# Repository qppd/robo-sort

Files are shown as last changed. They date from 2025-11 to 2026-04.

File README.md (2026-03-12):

# RoboSort: Advanced Automated Waste Segregation with AI Vision & LIDAR







## Overview
RoboSort is an intelligent automated waste segregation system designed to efficiently separate paper and plastic waste materials using a robotic arm, stepper motor positioning, and cutting-edge AI technology. The project addresses the growing need for automated waste management by combining computer vision, robotics, embedded systems, and LIDAR sensing to accurately identify and sort recyclable materials.

Integrating both Arduino and Raspberry Pi platforms, RoboSort combines mechanical, electrical, and software components for a robust, scalable solution suitable for educational institutions, recycling facilities, and smart waste management applications. The system now features advanced YOLO-based object detection, 360° LIDAR environmental awareness, and ROS2-based autonomous navigation with LiDAR odometry for precise robot localization and mapping.

## Table of Contents
- [Overview](#overview)
- [Architecture](#architecture)
- [System Diagrams](#system-diagrams)
- [Serial Communication Protocol](#serial-communication-protocol)
- [Features](#features)
- [Hardware Requirements](#hardware-requirements)
- [Software Components](#software-components)
- [Installation](#installation)
- [Usage](#usage)
- [Wiring Diagram](#wiring-diagram)
- [Hardware Models](#hardware-models)
- [Project Structure](#project-structure)
- [AI Vision System Configuration](#ai-vision-system-configuration)
- [Configuration](#configuration)
- [System Integration](#system-integration)
- [ROS2 Integration & LiDAR Odometry](#ros2-integration--lidar-odometry)
- [Diagrams Folder](#diagrams-folder)
- [Development](#development)
- [Contributing](#contributing)
- [License](#license)
- [Contact](#contact)

## Architecture
The system follows a modular, three-tier architecture:
- **Low-level control**: Arduino microcontroller manages real-time servo operations, motor control, and hardware interfacing
- **High-level logic**: Raspberry Pi handles vision processing, material classification (paper vs plastic), decision-making, and network communication
- **AI Vision & Sensing**: Advanced YOLO object detection with LIDAR environmental awareness for precise material identification and obstacle avoidance
- **Communication**: Serial protocol enables bidirectional data exchange between Arduino and Raspberry Pi for coordinated waste sorting operations

## Serial Communication Protocol

### Raspberry Pi ↔ Arduino Mega USB Communication

The system uses serial communication over USB cable for bidirectional data exchange between the Raspberry Pi (high-level logic) and Arduino Mega (low-level control). This architecture provides reliable, real-time control of robotic components.

#### Technical Specifications
- **Interface**: USB Serial (Virtual COM Port)
- **Baud Rate**: 9600 bps
- **Data Bits**: 8
- **Parity**: None
- **Stop Bits**: 1
- **Flow Control**: None
- **Protocol**: ASCII text commands with newline termination

#### Connection Setup
1. **Hardware Connection**: Connect Arduino Mega to Raspberry Pi USB port using USB cable
2. **Port Identification**:
   - Linux/Raspberry Pi: `/dev/ttyACM0` or `/dev/ttyUSB0`
   - Windows: `COM3`, `COM4`, etc.
3. **Permissions**: Add user to `dialout` group for serial access
   ```bash
   sudo usermod -a -G dialout $USER
   ```

#### Communication Flow
```
Raspberry Pi (Python) → Serial USB → Arduino Mega → Hardware Control
Raspberry Pi (Python) ← Serial USB ← Arduino Mega ← Sensor Feedback
```

#### Command Format
- **Commands**: ASCII text strings ending with newline (`\n`)
- **Response**: Immediate acknowledgment or data return
- **Timeout**: 1 second read timeout
- **Error Handling**: Automatic reconnection on communication failure

## Features

### Core Capabilities
- **Differential Drive Robot**: Arduino Mega-controlled DC motors with L298N H-bridge drivers for autonomous navigation
- **360° LiDAR Sensing**: LD06 sensor providing 0.02-12m range scanning at 4500Hz sample rate
- **ROS2 Integration**: Complete ROS2 Jazzy workspace with simulation and hardware control
- **LiDAR Odometry**: RF2O laser odometry for accurate robot localization without wheel encoders
- **SLAM Mapping**: Real-time simultaneous localization and mapping with SLAM Toolbox
- **Autonomous Navigation**: Nav2-based path planning and obstacle avoidance

### Robotics & Control
- **Five Degrees of Freedom Arm**: Articulated manipulator for precise waste material handling
- **Stepper Motor Positioning**: TB6600 driver with NEMA 23 motor (19kg/cm holding torque) for bin rotation
- **Servo Control**: PCA9685 16-channel PWM driver managing multiple servos via I2C
- **Differential Drive Kinematics**: Coordinated wheel control for omnidirectional movement
- **Software PWM**: Custom implementation for motor speed control with 10-second safety timeout

### Vision & Perception
- **YOLO Object Detection**: Real-time waste classification with confidence scoring
- **Multi-Source Input**: USB cameras, Raspberry Pi Camera, video files, and image processing
- **Distance-Aware Detection**: LiDAR measurements integrated with visual detection
- **Performance Monitoring**: FPS tracking and object counting

### System Architecture
- **Modular Design**: Clear separation between Arduino control and Raspberry Pi high-level logic
- **Serial Communication**: 9600 baud USB serial protocol for Arduino-Pi coordination
- **Gazebo Simulation**: Full physics simulation for testing and development
- **Expandable Platform**: Support for additional sensors and actuators
- **Comprehensive Documentation**: Complete installation, usage, and troubleshooting guides

## Hardware Requirements

### Main Body Dimensions
- Height: 4 inches
- Length: 35 inches
- Width: 20 inches

### Trash Bin Dimensions
- Height: 20 inches
- Radius: 10 inches (Diameter: 20 inches)

### Components
- **Robotic Arm**: 5-DOF articulated arm
- **Servos**: 5 standard servos (SG90/MG996R or similar)
- **Servo Driver**: Adafruit 16-channel PWM Servo Driver (PCA9685)
  - I2C interface requiring only 2 pins (SDA, SCL)
  - 12-bit resolution PWM output
  - Adjustable frequency up to 1.6 kHz
  - Chainable up to 62 boards (992 servos total)
  - I2C address: 0x40-0x7F (selectable via solder jumpers)
  - 5V tolerant logic (works with 3.3V or 5V systems)
  - Built-in clock for free-running PWM (no continuous signal needed)
- **Stepper Motor Driver**: TB6600 stepper motor driver for precise positioning
- **Stepper Motors**: NEMA 23 stepper motor (19kg/cm holding torque)
- **DC Motor Drivers**: Two L298N motor driver modules for DC motor control
- **DC Motors**: Two DC motors compatible with L298N drivers
- **LIDAR Sensors**:
  - **LDRobot LD06**: 360° scanning LIDAR (0.02-12m range, 4500Hz sample rate)
- **Camera Systems**:
  - USB webcam or Raspberry Pi Camera for object detection
  - Support for multiple resolutions and video formats
- **Microcontroller**: Arduino-compatible board (Uno, Mega, etc.)
- **Single-board Computer**: Raspberry Pi (any model with GPIO, recommended 4B+ for AI processing)
- **Power Supply**: Adequate power for servos, stepper motors, LIDAR, and logic circuits (recommend separate power for motors)

## Software Components

### Arduino Firmware
- **RoboSort.ino**: Main firmware integrating servo, stepper, and motor control with serial command interface
- **SERVO_CONFIG.h/.cpp**: Servo control logic with PCA9685 PWM driver and OE enable control
- **TB6600.h/.cpp**: TB6600 stepper motor driver implementation with blocking and non-blocking stepping
- **DC_CONFIG.h/.cpp**: DC motor control for L298N motor driver modules
- **ULTRASONIC_CONFIG.h/.cpp**: HC-SR04 ultrasonic sensor distance measurement

### Raspberry Pi Software
- **RoboSort.py**: Main application with interactive command-line interface for testing and controlling the robot
- **serial_config.py**: Modular serial communication handler for Arduino-Raspberry Pi USB communication
- **yolo_detect.py**: Advanced AI vision system with YOLO object detection and LIDAR integration
- **requirements.txt**: Python package dependencies

### AI Vision System (yolo_detect.py)
The YOLO detection system provides advanced computer vision capabilities:

#### Core Features
- **Multi-Source Input**: Support for USB cameras, Raspberry Pi Camera, video files, images, and image folders
- **Real-time Object Detection**: YOLO-based classification with confidence scoring
- **LIDAR Integration**: Distance measurement overlay on detected objects
- **360° Environmental Awareness**: Full point cloud data from LD06 LIDAR
- **Performance Monitoring**: FPS tracking and object counting
- **Recording Capabilities**: Save detection results as video files

#### Supported LIDAR Sensors
- **LD06 (LDRobot)**: 360° scanning LIDAR with 0.02-12m range

#### Command Line Interface
```bash
# Basic YOLO detection
python yolo_detect.py --model model.pt --source usb0 --resolution 640x480

# With LD06 LIDAR integration
python yolo_detect.py --model model.pt --source usb0 --lidar /dev/ttyUSB0 --lidar-type ld06

# With TFMini LIDAR
python yolo_detect.py --model model.pt --source usb0 --lidar COM3 --lidar-type tfmini

# Record results
python yolo_detect.py --model model.pt --source usb0 --record --resolution 640x480
```

### Serial Commands

#### Servo Commands
- `TEST`: Runs a test sequence on all servos
- `S<servo> <angle>`: Sets a specific servo (0-4) to a given angle (0-180)
  - Example: `S2 90` - Set servo 2 to 90 degrees

#### Stepper Motor Commands
- `BIN_HOME`: **Bin homing command** - Rotates CCW until BIN limit switch is triggered
  - Measures and displays exact steps to home position
  - **Correct command for bin operation CCW rotation**
  - Example output: "Exact steps to home position: 2347"
- `BIN_1`: Move to bin 1 position (950 steps CW)
- `BIN_2`: Move to bin 2 position (1900 steps CW)
- `BIN_3`: Move to bin 3 position (2850 steps CW)
- `BIN_4`: Move to bin 4 position (3800 steps CW)

**Bin Operation Commands:**
- `BIN_HOME` - Rotate CCW to home position (limit switch triggered)
- `BIN_1` - Move to bin 1 position (quarter rotation: 950 steps)
- `BIN_2` - Move to bin 2 position (half rotation: 1900 steps)
- `BIN_3` - Move to bin 3 position (three-quarter rotation: 2850 steps)
- `BIN_4` - Move to bin 4 position (full rotation: 3800 steps)

#### Ultrasonic Commands
- `UTEST`: Runs comprehensive ultrasonic sensor test with multiple readings
- `UDIST`: Gets single distance measurement in centimeters
- `UAVG <samples>`: Gets average distance from multiple samples (1-10)
  - Example: `UAVG 5` - Average of 5 distance samples
- `UDETECT <threshold>`: Detects if object is within threshold distance (1-400 cm)
  - Example: `UDETECT 30` - Detect objects within 30 cm

## Installation

### Arduino Setup
1. Install the Arduino IDE from [arduino.cc](https://www.arduino.cc)
2. Install the Adafruit PWM Servo Driver library:
   - Open Arduino IDE
   - Go to Tools > Manage Libraries
   - Search for "Adafruit PWM Servo Driver"
   - Install the library
3. Open `source/arduino/RoboSort/RoboSort.ino`
4. Select your board and port from the Tools menu
5. Upload the firmware to your Arduino

### Raspberry Pi Setup
1. Ensure Python 3.x is installed (pre-installed on Raspberry Pi OS)
2. Navigate to `source/rpi/RoboSort/`
3. Install required Python packages:
   ```bash
   pip install -r requirements.txt
   ```
   Or install packages individually:
   ```bash
   pip install pyserial ultralytics opencv-python numpy
   ```
4. **For LIDAR Support** (optional, install as needed):
   ```bash
   # For LD06 serial LIDAR (pyserial already included)
   # No additional packages needed
   ```
5. Configure serial port permissions:
   ```bash
   sudo usermod -a -G dialout $USER
   ```
   Then logout and login again for changes to take effect
6. **Serial Communication Setup**:
   - Connect Arduino Mega to Raspberry Pi via USB cable
   - The Arduino will appear as a serial device (typically `/dev/ttyACM0`)
   - Baud rate: 9600 (automatically configured)
   - Test connection:
   ```bash
   ls /dev/ttyACM* /dev/ttyUSB*
   ```
7. Run the Python application:
   ```bash
   python3 RoboSort.py
   ```

### YOLO Model Setup
1. Download or train a YOLO model for waste classification
2. Place the model file (`.pt` format) in the `source/rpi/RoboSort/` directory
3. Supported models: YOLOv8, YOLOv9, YOLOv10, or custom trained models

### LIDAR Sensor Setup
1. **LD06 Setup**:
   - Connect to USB port (appears as `/dev/ttyUSB0` on Linux or `COM3` on Windows)
   - Baudrate: 230400
   - No additional configuration needed

### ROS2 Workspace Setup (Advanced Features)
1. **Install ROS2 Jazzy**:
   ```bash
   # Follow official ROS2 installation guide for Ubuntu
   sudo apt update
   sudo apt install ros-jazzy-desktop ros-jazzy-vision-msgs ros-jazzy-cv-bridge
   ```

2. **Build RoboSort ROS2 Workspace**:
   ```bash
   cd ~/robo-sort/source/rpi/ros2-robosort
   source /opt/ros/jazzy/setup.bash
   colcon build --symlink-install
   source install/setup.bash
   ```

3. **Install RF2O Laser Odometry** (for LiDAR-based odometry):
   ```bash
   sudo apt install ros-jazzy-rf2o-laser-odometry
   ```

## Usage

### AI Vision System (YOLO Detection)

The `yolo_detect.py` script provides advanced object detection and LIDAR integration capabilities:

#### Basic Usage
```bash
# Detect objects from USB camera
python yolo_detect.py --model yolov8n.pt --source usb0

# Detect from Raspberry Pi Camera
python yolo_detect.py --model yolov8n.pt --source picamera0 --resolution 640x480

# Process video file
python yolo_detect.py --model yolov8n.pt --source video.mp4

# Process single image
python yolo_detect.py --model yolov8n.pt --source image.jpg

# Process image folder
python yolo_detect.py --model yolov8n.pt --source images/
```

#### LIDAR Integration
```bash
# LD06 360° LIDAR (recommended for full environmental awareness)
python yolo_detect.py --model yolov8n.pt --source usb0 --lidar /dev/ttyUSB0 --lidar-type ld06
```

#### Advanced Options
```bash
# Custom confidence threshold
python yolo_detect.py --model yolov8n.pt --source usb0 --thresh 0.3

# Record detection results
python yolo_detect.py --model yolov8n.pt --source usb0 --record --resolution 640x480

# Custom display resolution
python yolo_detect.py --model yolov8n.pt --source usb0 --resolution 1280x720
```

#### Visual Output Features
- **Real-time Detection**: Bounding boxes with class labels and confidence scores
- **LIDAR Overlay**: Distance measurements displayed on screen and in detection labels
- **Performance Metrics**: FPS counter and object counting
- **360° Awareness**: LD06 provides closest obstacle distance from any direction
- **Safety Monitoring**: Forward distance for collision avoidance

#### Keyboard Controls
- **'q' or 'Q'**: Quit the application
- **'s' or 'S'**: Pause/resume detection
- **'p' or 'P'**: Save current frame as screenshot

### Raspberry Pi Interactive Control
The RoboSort.py application provides a menu-driven interface for controlling the system:

```bash
python3 RoboSort.py
```

**Menu Options:**
1. Test all servos
2. Set specific servo angle
3. Test stepper motor
4. Control stepper motor movement
5. Home stepper motor
6. Stop stepper motor
7. Test ultrasonic sensor
8. Get distance measurement
9. Detect object (with threshold)
10. Send custom command
0. Exit

### Arduino Stepper Motor Control

The Arduino Mega handles direct stepper motor control with precise positioning commands:

#### Bin Operation Commands
**Important: These are the calibrated commands for your specific stepper setup:**

- **`BIN_HOME`** - Rotate CCW until BIN limit switch is triggered
  - Measures exact steps to home position
  - Displays: "Exact steps to home position: [count]"
  - Use this to calibrate and find home position

- **`BIN_1`** - Rotate CW to bin 1 position (950 steps)
  - First bin position (quarter rotation)
  - 950 steps = 3800 / 4

- **`BIN_2`** - Rotate CW to bin 2 position (1900 steps)
  - Second bin position (half rotation)
  - 1900 steps = 3800 / 2

- **`BIN_3`** - Rotate CW to bin 3 position (2850 steps)
  - Third bin position (three-quarter rotation)
  - 2850 steps = 3800 * 3 / 4

- **`BIN_4`** - Rotate CW to bin 4 position (3800 steps)
  - Fourth bin position (full rotation)
  - 3800 steps = complete rotation

#### Stepper Command Reference
```
BIN_HOME               - CCW rotation until limit switch (homing)
BIN_1                  - CW rotation 950 steps (bin 1 - quarter rotation)
BIN_2                  - CW rotation 1900 steps (bin 2 - half rotation)
BIN_3                  - CW rotation 2850 steps (bin 3 - three-quarter rotation)
BIN_4                  - CW rotation 3800 steps (bin 4 - full rotation)
```

#### Example Usage
```bash
# Send commands via serial terminal or Python script
BIN_HOME               # Home to limit switch position
BIN_1                  # Move to bin 1 position
BIN_2                  # Move to bin 2 position
BIN_3                  # Move to bin 3 position
BIN_4                  # Move to bin 4 position
```

**Note:** All stepper commands now use slow, safe timing (750us pulse + 1500us gap) for precise control.

    # Control servo
    serial_conn.set_servo(0, 90)
    serial_conn.enable_servos()
    serial_conn.disable_servos()

    # Control stepper motor
    serial_conn.stepper_move(200, 0)  # Move 200 steps CW
    serial_conn.stepper_move(200, 1)  # Move 200 steps CCW
    serial_conn.stepper_stop()
```

### Arduino Serial Monitor Testing

**Basic Operation:**
1. Connect Arduino to computer via USB
2. Open Arduino IDE Serial Monitor (9600 baud)
3. Send commands directly to test components

**Testing Servos:**
```
TEST          # Run test sequence on all servos
S0 90         # Set servo 0 to 90 degrees
SENABLE       # Enable servo driver
SDISABLE      # Disable servo driver
STEST         # Start continuous test (5 sec at 0°, 5 sec at 180°)
SSTOP         # Stop continuous test
```

**Testing Stepper Motor:**
```
BIN_HOME      # Rotate CCW until BIN limit switch is triggered
BIN_1         # Move to bin 1 position (950 steps CW)
BIN_2         # Move to bin 2 position (1900 steps CW)
BIN_3         # Move to bin 3 position (2850 steps CW)
BIN_4         # Move to bin 4 position (3800 steps CW)
```

**Testing Ultrasonic Sensor:**
```
UTEST         # Run sensor test
UDIST         # Get single distance measurement
UAVG 5        # Get average of 5 samples
UDETECT 30    # Detect object within 30 cm threshold
UCTEST        # Start continuous monitoring for 20 seconds
UCSTOP        # Stop continuous monitoring
```

**Testing DC Motors:**
```
MTEST         # Test all motors
MA F 100      # Motor A forward at speed 100
MA B 150      # Motor A backward at speed 150
MA S          # Motor A stop
MA BR         # Motor A brake
MSTOP         # Stop all motors
MCTEST        # Start continuous back-and-forth test
MCSTOP        # Stop continuous test
```

**L298N Motor Control Notes:**
- **Forward**: IN1=HIGH, IN2=LOW
- **Backward**: IN1=LOW, IN2=HIGH
- **Stop**: IN1=LOW, IN2=LOW
- **Brake**: IN1=HIGH, IN2=HIGH (short-circuit brake)
- Speed controlled via PWM on ENA/ENB pins (0-255)

## ROS2 Integration & LiDAR Odometry

**For complete ROS2 setup instructions, LiDAR odometry configuration, and advanced features, see the [ROS2 Integration & LiDAR Odometry](#ros2-integration--lidar-odometry) section below.**

### Quick ROS2 Launch (Basic)
```bash
# Build workspace
cd ~/robo-sort/source/rpi/ros2-robosort
source /opt/ros/jazzy/setup.bash
colcon build --symlink-install
source install/setup.bash

# Launch with automated script
./start_robosort.sh
```

### Manual ROS2 Launch
```bash
# Terminal 1: Main system
ros2 launch robosort_control robosort.launch.py arduino_port:=/dev/ttyUSB0 lidar_port:=/dev/ttyUSB1 use_rviz:=true

# Terminal 2: SLAM mapping
ros2 launch slam_toolbox online_async_launch.py params_file:=config/mapper_params_online_async.yaml
```

## Wiring Diagram

### System Wiring Schematic
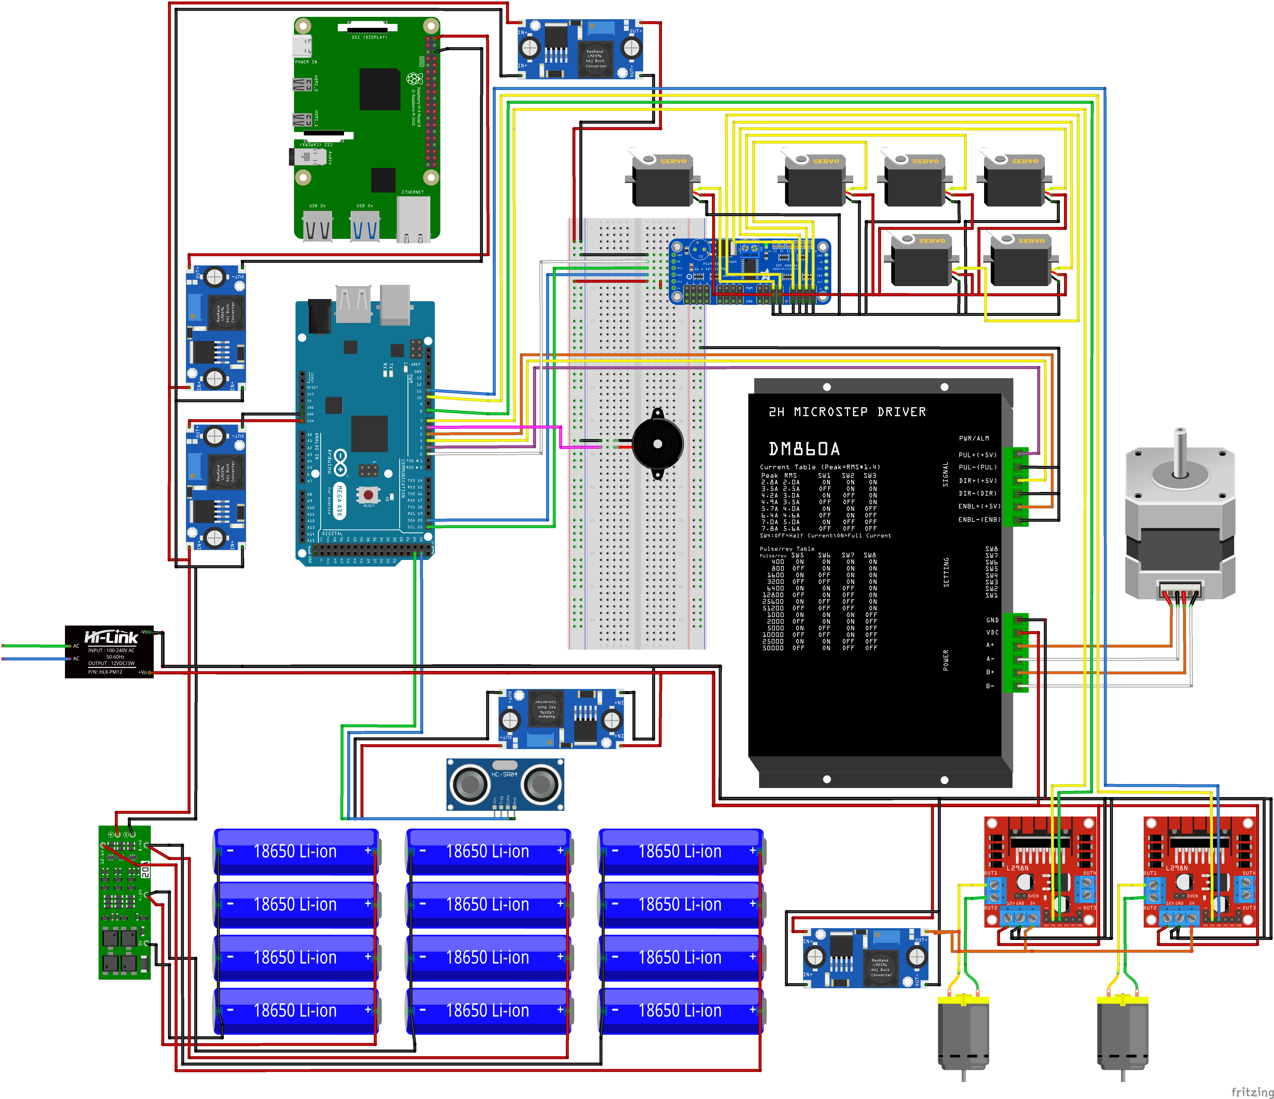
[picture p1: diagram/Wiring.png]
RoboSort Wiring Diagram


The wiring diagram shows the complete electrical connections for the RoboSort system. All components are connected to the Arduino Mega 2560 microcontroller, which serves as the central control unit. The Arduino communicates with the Raspberry Pi via USB serial connection for coordinated control.

#### System Communication:
**Arduino Mega ↔ Raspberry Pi Serial USB**
- **USB Cable**: Standard USB A-to-B cable (Arduino Mega uses USB-B connector)
- **Serial Port**: Appears as `/dev/ttyACM0` on Raspberry Pi
- **Baud Rate**: 9600 bps
- **Protocol**: ASCII command/response over virtual serial port

#### Component Connections:

**1. Adafruit PCA9685 16-Channel PWM Servo Driver**
- **VCC** → Arduino 5V
- **GND** → Arduino GND
- **SDA** → Arduino Pin 20 (SDA)
- **SCL** → Arduino Pin 21 (SCL)
- **OE** → Arduino Pin 2 (Output Enable, active low)
- **V+** → External 5V Power Supply (for servos)
- **GND** → Common Ground with external power
- **Servo Outputs** → 6 Servos connected to channels 0-5 (ch0: arm-rotate, ch1: extend, ch2: look, ch3: grip-rotator, ch4: gripper, ch5: lifter)

**2. TB6600 Stepper Motor Driver**
- **Control Pins:**
  - PUL+ → Arduino Pin 3 (pulse for each step)
  - DIR+ → Arduino Pin 4 (direction control)
  - ENA+ → Arduino Pin 5 (enable/disable, active low)
- **Power:**
  - VMOT → Motor power supply (DC power input)
  - GND → Common ground with Arduino
- **Motor Connections:**
  - A+ / A- / B+ / B- → NEMA 23 stepper motor coils

**3. DC Motor Drivers (L298N Modules)**
- **L298N Module 1 (Motor A):**
  - IN1 → Arduino Pin 7
  - IN2 → Arduino Pin 9
  - ENA → Arduino Pin 11 (PWM for speed control)
- **L298N Module 2 (Motor B):**
  - IN1 → Arduino Pin 10
  - IN2 → Arduino Pin 11
  - ENB → Arduino Pin 8 (PWM for speed control)
- **Power:** Separate power supply for motors (motor power connected to L298N modules)

**4. HC-SR04 Ultrasonic Sensor**
- **VCC** → Arduino 5V
- **GND** → Arduino GND
- **TRIG** → Arduino Pin 4
- **ECHO** → Arduino Pin 5

**4. Power Supply Configuration**
- **Arduino Power:** USB connection from Raspberry Pi or 7-12V DC adapter
- **Servo Power:** Separate 5V power supply (recommended 5V 5A for multiple servos)
- **Stepper Motor Power:** Separate power supply (8-35V depending on motor/driver)
- **Common Ground:** All grounds must be connected together

#### Important Notes:
- Always use separate power supplies for stepper motors and servos to prevent voltage drops
- Ensure proper stepper motor coil wiring (check motor datasheet)
- Set appropriate current limiting on stepper driver to prevent overheating
- Use shielded cables for STEP and DIR signals if experiencing interference
- Ensure all grounds are connected together (common ground)
- The Fritzing source file (`Wiring.fzz`) is available in the `diagram/` folder for editing
- Verify all connections before powering on the system
- Use appropriate wire gauges for motor connections (minimum 22 AWG)

## Hardware Models

### Front View
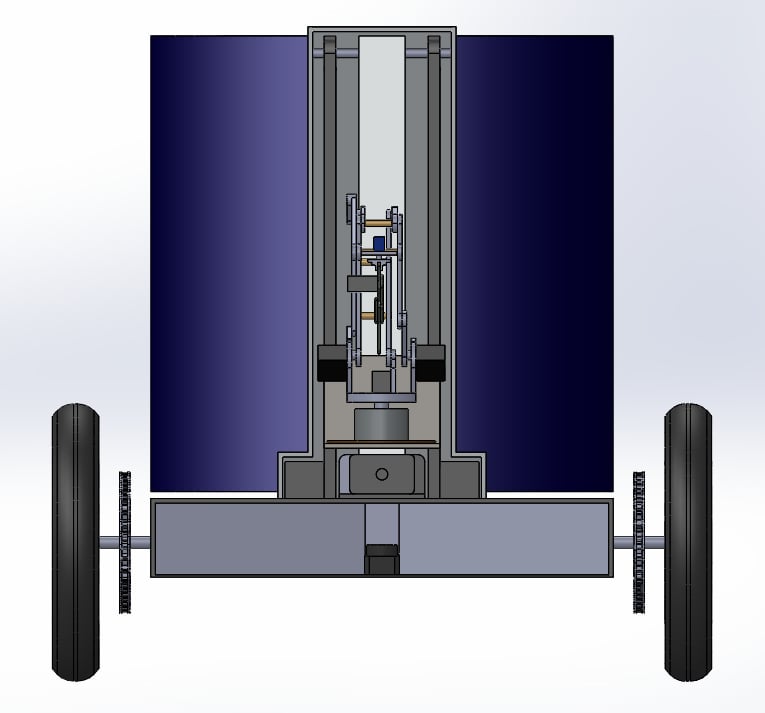
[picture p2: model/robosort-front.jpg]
RoboSort Front View


The front view shows the main interface and access points of the RoboSort system, including the entry slot for sorting and the control panel.

### Side View
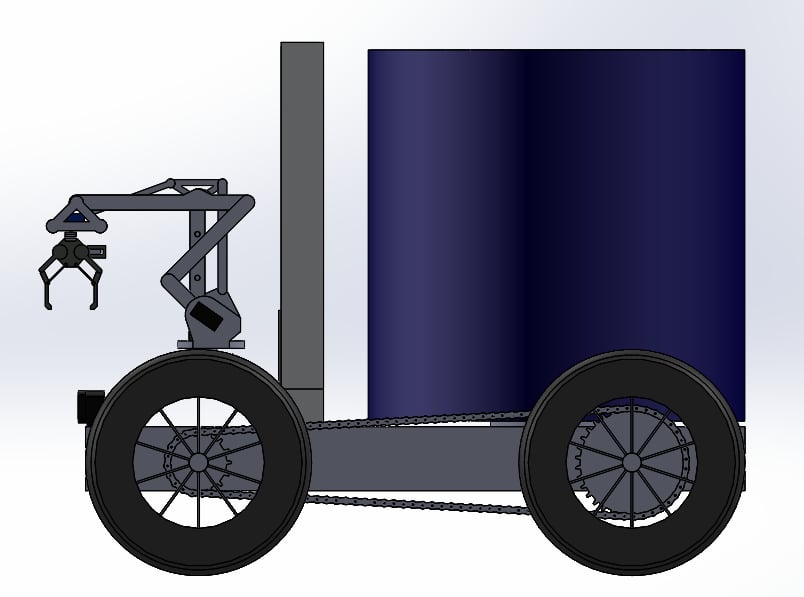
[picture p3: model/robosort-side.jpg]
RoboSort Side View


The side view highlights the internal mechanism layout, conveyor system, and the relative position of the trash bin to the sorting area.

### Main/Top View
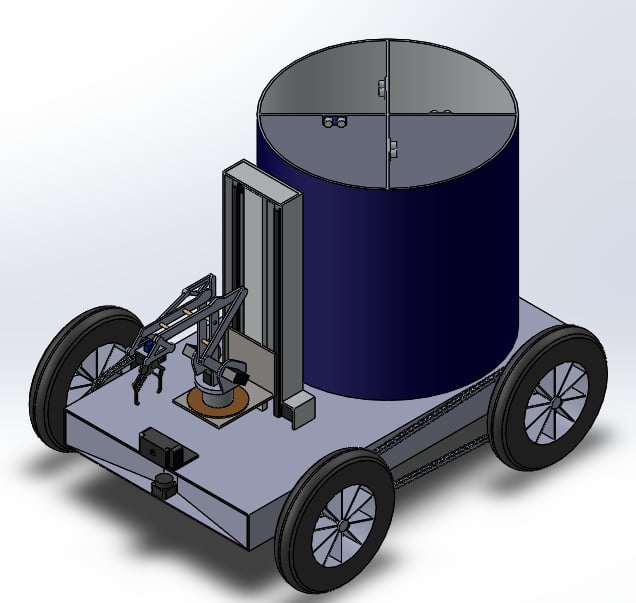
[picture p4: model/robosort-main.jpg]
RoboSort Main View


The main/top view provides a comprehensive look at the overall structure, showing the arrangement of components and the spatial relationship between the body and the trash bin.

### RoboSort Lidar Mount
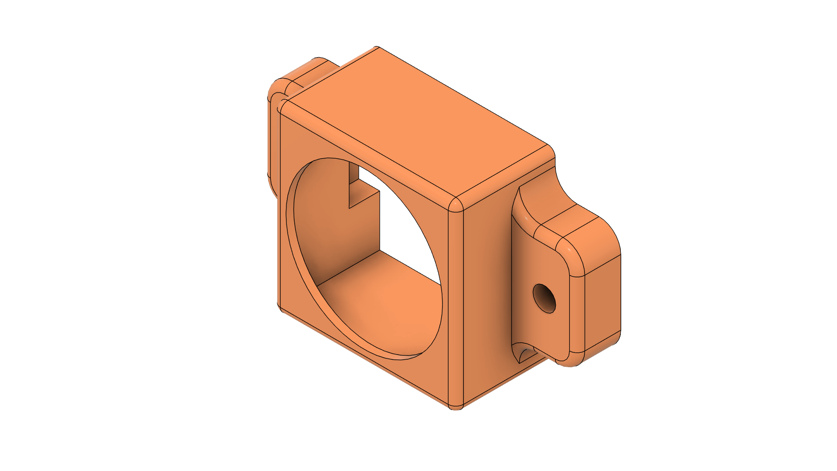
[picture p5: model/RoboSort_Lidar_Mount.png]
RoboSort Lidar Mount


**Description:**
The RoboSort Lidar Mount is a custom-designed 3D-printed bracket specifically engineered to securely hold the LD06 360° LIDAR sensor on the RoboSort platform. This mount ensures optimal sensor alignment and vibration isolation, which are critical for accurate distance measurements and reliable 360° environmental scanning.

**Key Features:**
- **Precision Fit:** Designed to match the LD06 LIDAR's mounting holes and base diameter for a snug, secure fit.
- **Vibration Dampening:** Includes anti-vibration pads or mounting holes for rubber grommets to minimize sensor noise.
- **Cable Management:** Integrated channels or clips for neat routing of power and data cables.
- **Adjustable Height:** Allows fine-tuning of the LIDAR's elevation for best field of view and obstacle clearance.
- **Material:** Recommended to print in PETG or ABS for strength and heat resistance.
- **Mounting:** Attaches to the main platform using M3 screws and heat-set inserts for robust, repeatable installation.

**Usage:**
- Place the LD06 LIDAR into the mount, align the holes, and secure with screws.
- Route the cables through the provided channels to prevent tangling or snagging during arm movement.
- The mount is positioned to provide a clear 360° scan without obstruction from the robotic arm or bins.

**Section Reference:** See also the [3D Model Documentation](diagrams/3d_model_specification.md) for technical details and print settings.

---

### RoboSort Limit Switch Mount
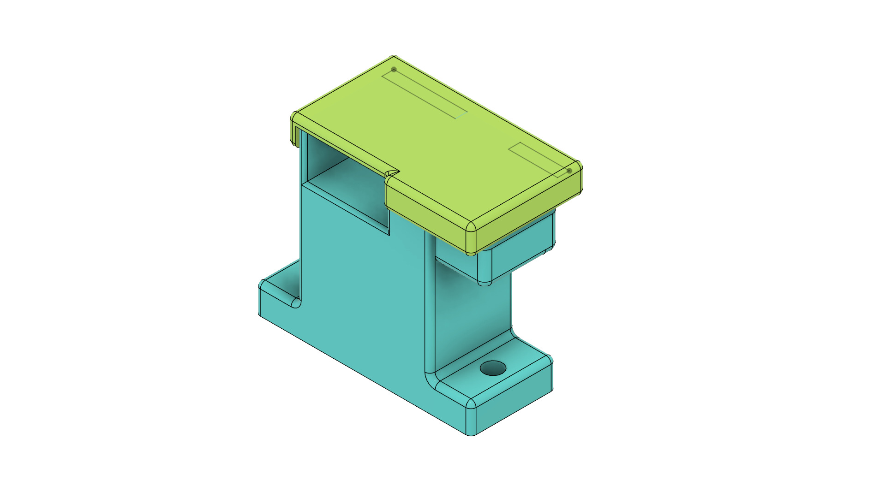
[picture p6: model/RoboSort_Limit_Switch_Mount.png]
RoboSort Limit Switch Mount


**Description:**
The RoboSort Limit Switch Mount is a custom-designed 3D-printed bracket engineered to securely hold limit switches (end-stop sensors) on the RoboSort platform. This mount provides precise positioning for homing and boundary detection in stepper motor systems, ensuring accurate and safe robotic movement.

**Key Features:**
- **Precision Alignment:** Designed with adjustable slots or holes for fine-tuning switch position and activation point.
- **Secure Mounting:** Includes mounting holes for M3 screws and heat-set inserts for robust attachment to the frame.
- **Cable Management:** Integrated channels or clips for organizing switch wiring and preventing cable strain.
- **Universal Compatibility:** Supports standard microswitches or optical limit switches commonly used in robotics.
- **Material:** Recommended to print in PETG or ABS for durability and dimensional stability.
- **Adjustable Trigger:** Allows precise adjustment of the switch activation distance for optimal performance.

**Usage:**
- Mount the limit switch into the bracket and secure with screws.
- Position the mount at the desired end-stop location on the linear rail or stepper motor axis.
- Adjust the switch position to trigger at the correct boundary point.
- Connect the switch to the Arduino for homing and safety limit detection.

**Section Reference:** See also the [3D Model Documentation](diagrams/3d_model_specification.md) for technical details and print settings.

---

### RoboSort Plate
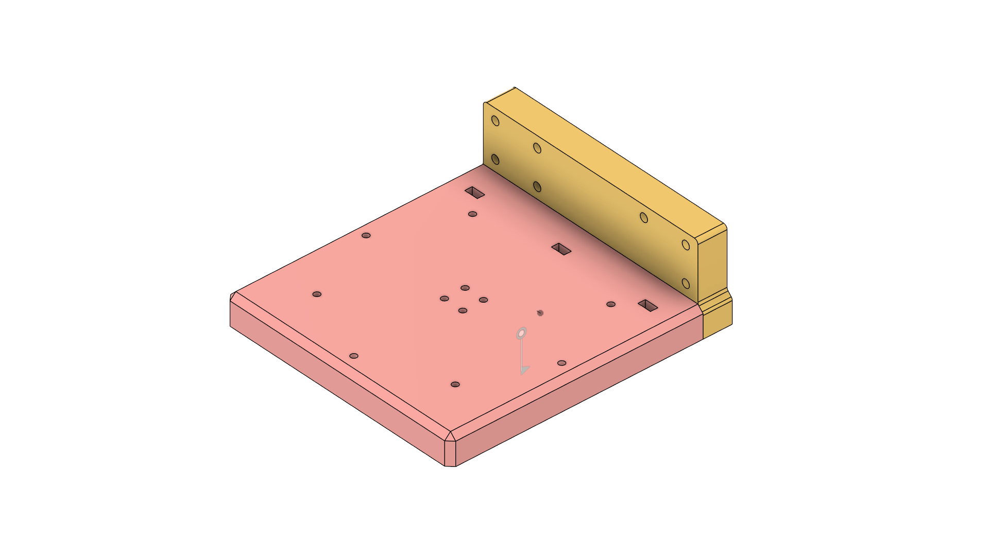
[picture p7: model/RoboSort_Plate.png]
RoboSort Plate


**Description:**
The RoboSort Plate is a custom-designed 3D-printed platform component specifically engineered for the up and down mechanism of the robotic arm. This plate serves as the primary surface for holding and positioning waste materials during the vertical movement and sorting process, ensuring stable material handling throughout the arm's operation.

**Key Features:**
- **Vertical Mechanism Integration:** Specifically designed to work with the robotic arm's up/down movement system.
- **Stable Platform:** Provides a flat, reliable surface for material placement during vertical translation.
- **Lightweight Design:** Optimized weight distribution to reduce load on servos and motors during vertical movement.
- **Material Compatibility:** Designed to handle various waste materials (paper, plastic) without deformation.
- **Material:** Recommended to print in PETG or ABS for strength, durability, and heat resistance.
- **Precision Fit:** Engineered to integrate seamlessly with the Plate Holder for complete mechanism operation.

**Usage:**
- Install the plate onto the robotic arm's vertical mechanism assembly.
- Ensure proper alignment with the Plate Holder for smooth up/down movement.
- The plate moves vertically with the arm to position materials at different heights for sorting.
- Works in conjunction with the gripper system for material transfer.

**Section Reference:** See also the [3D Model Documentation](diagrams/3d_model_specification.md) for technical details and print settings.

---

### RoboSort Plate Holder
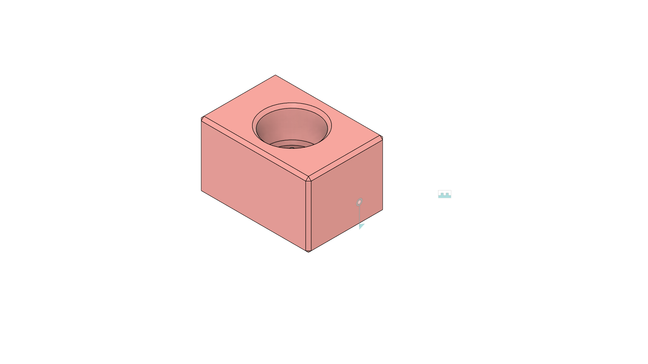
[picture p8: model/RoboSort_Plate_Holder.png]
RoboSort Plate Holder


**Description:**
The RoboSort Plate Holder is a custom-designed 3D-printed bracket specifically engineered to securely hold the RoboSort Plate as part of the robotic arm's up and down mechanism. This holder provides the structural support and guidance system for the vertical movement of the plate, ensuring stable positioning of waste materials during the entire sorting process and preventing slippage during arm operations.

**Key Features:**
- **Up/Down Mechanism Component:** Essential part of the robotic arm's vertical movement system.
- **Secure Grip:** Designed with retention features or clamps to hold the plate firmly in place during vertical motion.
- **Adjustable Positioning:** Includes slots or holes for fine-tuning plate alignment and height settings.
- **Vibration Resistance:** Features anti-slip surfaces or rubber inserts to minimize plate movement during operation.
- **Modular Design:** Allows for easy assembly and maintenance of the vertical mechanism.
- **Material:** Recommended to print in PETG or ABS for strength and wear resistance.
- **Mounting:** Attaches to the robotic arm structure using M3 screws and heat-set inserts for stable installation.

**Usage:**
- Attach the holder to the robotic arm's vertical actuation system.
- Place the RoboSort Plate into the holder and secure with mounting hardware.
- Mount the assembly on the designated arm location for material staging.
- Ensure the plate is level and properly aligned for smooth vertical movement.
- The holder maintains plate position during the entire up/down sorting cycle.

**Section Reference:** See also the [3D Model Documentation](diagrams/3d_model_specification.md) for technical details and print settings.

---

### RoboSort Bearing Bin Guide Mount
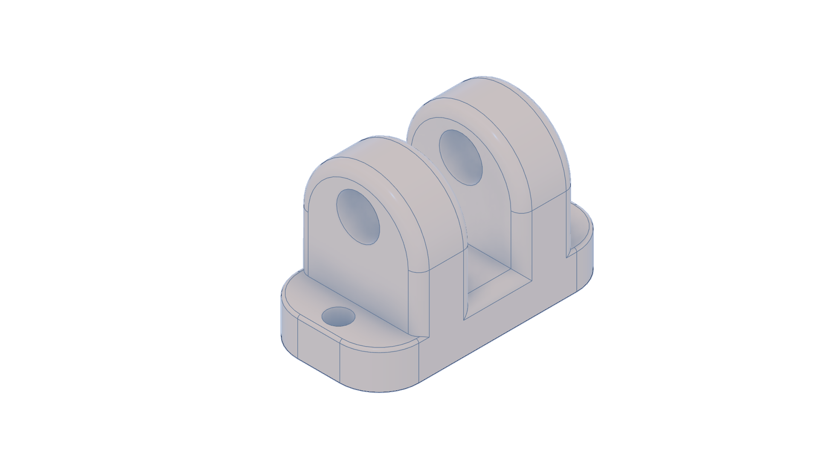
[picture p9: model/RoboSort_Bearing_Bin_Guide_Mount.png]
RoboSort Bearing Bin Guide Mount


**Description:**
The RoboSort Bearing Bin Guide Mount is a custom-designed 3D-printed bracket specifically engineered to securely hold bearings and guide rails for the bin mechanism in the RoboSort platform. This mount provides precise alignment and support for smooth linear motion of the sorting bins, ensuring accurate positioning during waste segregation operations.

**Key Features:**
- **Precision Alignment:** Designed with exact tolerances for bearing and guide rail installation.
- **Secure Mounting:** Includes mounting holes for M3 screws and heat-set inserts for robust attachment.
- **Vibration Resistance:** Features designed to minimize vibration and ensure smooth operation.
- **Modular Design:** Allows for easy assembly and maintenance of the bin mechanism.
- **Material:** Recommended to print in PETG or ABS for strength and durability.
- **Mounting:** Attaches to the RoboSort frame using standard fasteners.

**Usage:**
- Install bearings and guide rails into the mount according to specifications.
- Mount the assembly on the designated frame location for bin guidance.
- Ensure proper alignment for smooth linear motion of the sorting bins.

**Section Reference:** See also the [3D Model Documentation](diagrams/3d_model_specification.md) for technical details and print settings.

---

### RoboSort Bin Gear
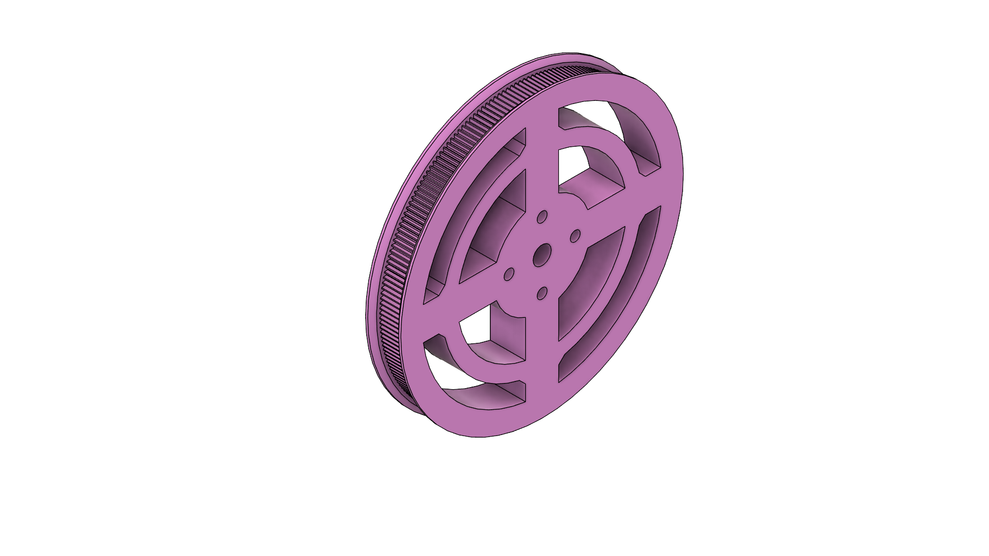
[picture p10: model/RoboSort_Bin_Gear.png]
RoboSort Bin Gear


**Description:**
The RoboSort Bin Gear is a custom-designed 3D-printed gear component specifically engineered for the bin rotation mechanism in the RoboSort platform. This gear provides the necessary torque transmission and rotational motion for sorting bins, ensuring precise positioning during waste segregation operations.

**Key Features:**
- **Precision Teeth:** Designed with accurate gear teeth for smooth and reliable rotation.
- **Secure Mounting:** Includes mounting holes for M3 screws and heat-set inserts for robust attachment.
- **Torque Transmission:** Optimized for efficient power transfer from the motor to the bin mechanism.
- **Modular Design:** Allows for easy integration with the bin rotation system.
- **Material:** Recommended to print in PETG or ABS for strength and wear resistance.
- **Mounting:** Attaches to the RoboSort bin assembly using standard fasteners.

**Usage:**
- Install the gear onto the bin rotation shaft according to specifications.
- Ensure proper meshing with the drive gear for optimal performance.
- Mount the assembly on the designated bin location for rotational sorting.

**Section Reference:** See also the [3D Model Documentation](diagrams/3d_model_specification.md) for technical details and print settings.

---

### RoboSort Ultrasonic Case
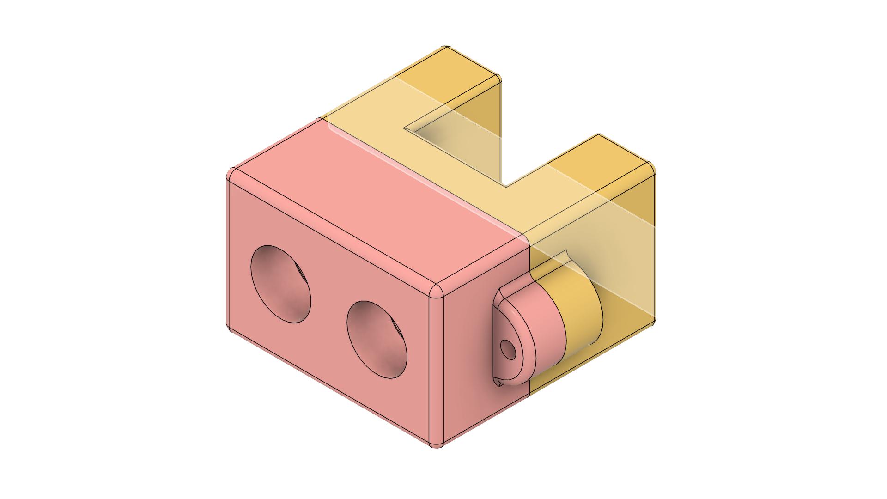
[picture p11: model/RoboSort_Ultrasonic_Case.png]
RoboSort Ultrasonic Case


**Description:**
The RoboSort Ultrasonic Case is a custom-designed 3D-printed enclosure specifically engineered to securely house and mount an HC-SR04 or similar ultrasonic sensor on the RoboSort platform. This case provides optimal sensor alignment, vibration isolation, and cable management for accurate distance measurements and reliable obstacle detection.

**Key Features:**
- **Precision Fit:** Designed to match the HC-SR04 sensor's dimensions for a snug, secure fit.
- **Vibration Dampening:** Includes mounting features to minimize sensor noise during operation.
- **Cable Management:** Integrated channels for neat routing of power and signal cables.
- **Adjustable Orientation:** Allows fine-tuning of sensor angle for best detection range.
- **Material:** Recommended to print in PETG or ABS for durability and dimensional stability.
- **Mounting:** Attaches to the RoboSort frame using M3 screws and heat-set inserts.

**Usage:**
- Place the HC-SR04 sensor into the case, align the pins, and secure with screws.
- Route the cables through the provided channels to prevent tangling.
- Mount the case on the designated frame location for optimal sensor positioning.

**Section Reference:** See also the [3D Model Documentation](diagrams/3d_model_specification.md) for technical details and print settings.

---

### RoboSort Servo Driver Mount
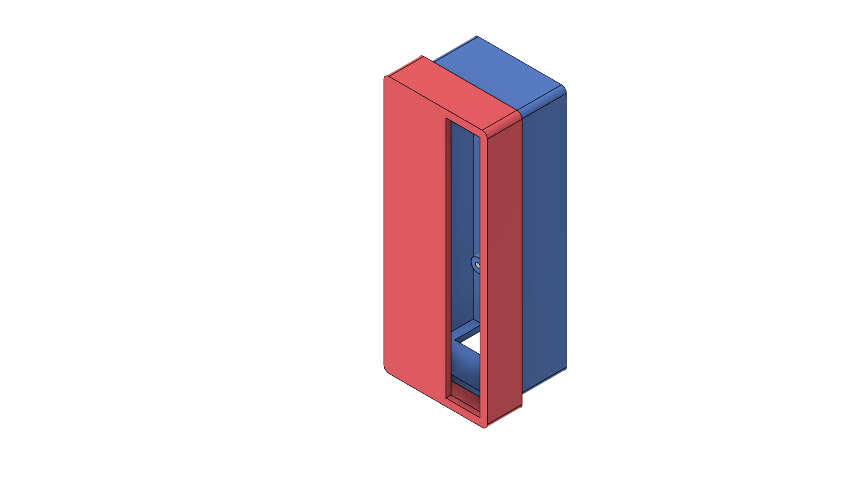
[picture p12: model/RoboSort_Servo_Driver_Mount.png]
RoboSort Servo Driver Mount


**Description:**
The RoboSort Servo Driver Mount is a custom-designed 3D-printed bracket specifically engineered to securely hold and position the Adafruit PCA9685 16-channel PWM servo driver on the RoboSort platform. This mount provides stable support and optimal orientation for the servo driver board, ensuring reliable PWM signal generation for coordinated multi-servo control during robotic arm operations. The mount works in conjunction with the servo system to provide precise positioning and movement control for the robotic arm and lifter mechanisms.

**Key Features:**
- **Precision Alignment:** Designed with exact tolerances to securely hold the PCA9685 servo driver board.
- **Heat Dissipation:** Includes ventilation features to prevent overheating during continuous operation.
- **Cable Management:** Integrated channels or clips for organizing power and signal cables.
- **Vibration Isolation:** Features designed to minimize vibration transmission to the servo driver.
- **Secure Mounting:** Includes mounting holes for M3 screws and heat-set inserts for robust attachment.
- **Modular Design:** Allows for easy access to the servo driver for maintenance and reprogramming.
- **Material:** Recommended to print in PETG or ABS for strength, durability, and heat resistance.

**Usage:**
- Position the PCA9685 servo driver board into the mount and secure with screws.
- Route the power and signal cables through the provided channels to prevent interference.
- Mount the assembly on the designated frame location for optimal servo control positioning.
- Ensure proper ventilation around the servo driver for heat dissipation.
- Connect servo signal wires to the appropriate channels for robotic arm and lifter control.
- The mount provides stable support during continuous servo operation cycles.

**Section Reference:** See also the [3D Model Documentation](diagrams/3d_model_specification.md) for technical details and print settings.

---

### RoboSort Lifter Servo Coupling Adapter
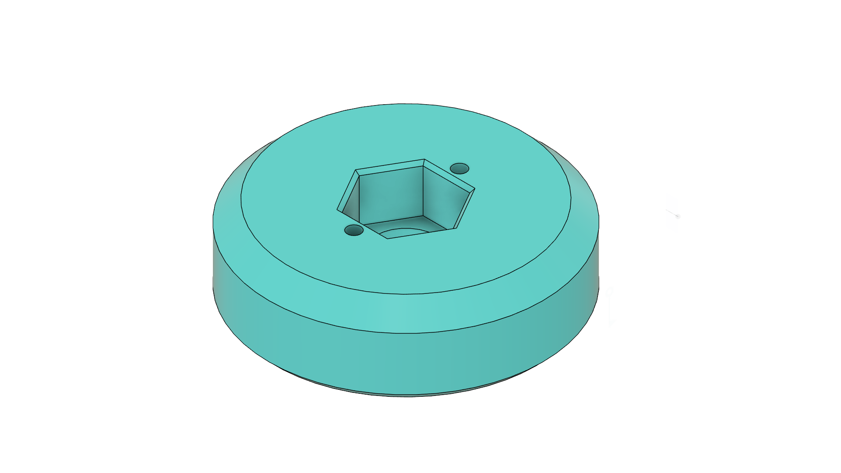
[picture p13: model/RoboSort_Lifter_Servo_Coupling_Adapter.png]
RoboSort Lifter Servo Coupling Adapter


**Description:**
The RoboSort Lifter Servo Coupling Adapter is a custom-designed 3D-printed coupling component specifically engineered to connect the servo motor to the lifter mechanism in the RoboSort platform. This adapter provides a secure and precise interface between the servo output shaft and the lifting system's drive components, ensuring efficient power transmission and accurate vertical movement control.

**Key Features:**
- **Precision Coupling:** Designed with exact tolerances to match servo motor shaft dimensions and lifter drive requirements.
- **Torque Transmission:** Optimized geometry for maximum torque transfer from servo to lifting mechanism.
- **Backlash Minimization:** Features anti-backlash design to reduce play and improve positioning accuracy.
- **Material Compatibility:** Compatible with standard servo motors and lifting system components.
- **Material:** Recommended to print in PETG or ABS for strength and wear resistance.
- **Mounting:** Integrates seamlessly with servo motors and lifter assembly using set screws or press-fit connections.

**Usage:**
- Attach the adapter to the servo motor output shaft and secure with set screws.
- Connect the adapter to the lifter mechanism's drive input.
- Ensure proper alignment to prevent binding during operation.
- The adapter transmits servo rotation to linear lifting motion for material handling.

**Section Reference:** See also the [3D Model Documentation](diagrams/3d_model_specification.md) for technical details and print settings.

---

### RoboSort Lifter Servo Mount
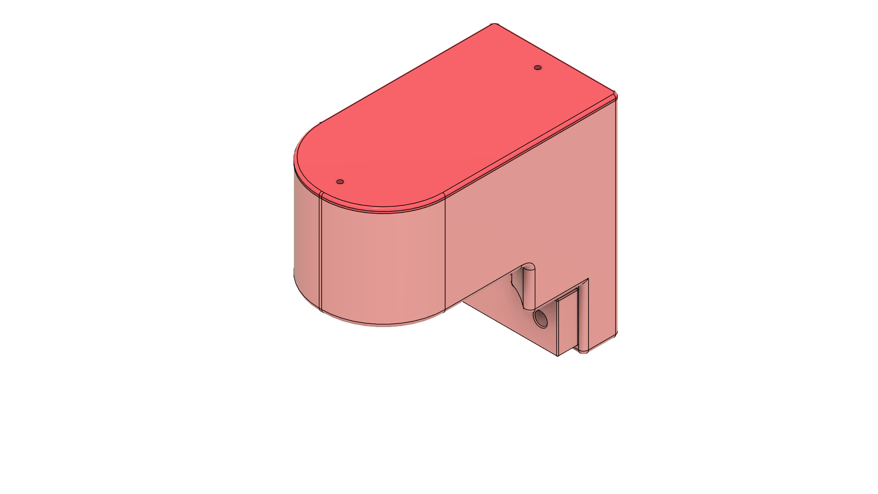
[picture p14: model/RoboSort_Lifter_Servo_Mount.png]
RoboSort Lifter Servo Mount


**Description:**
The RoboSort Lifter Servo Mount is a custom-designed 3D-printed bracket specifically engineered to securely hold and position the servo motor responsible for the lifter mechanism in the RoboSort platform. This mount provides stable support and precise alignment for the servo, ensuring optimal performance of the vertical lifting system during waste sorting operations.

**Key Features:**
- **Precision Alignment:** Designed with exact tolerances to match standard servo motor dimensions for secure, wobble-free mounting.
- **Vibration Dampening:** Includes features to minimize servo vibration during operation, improving control accuracy.
- **Cable Management:** Integrated channels or clips for organizing servo power and signal cables.
- **Adjustable Positioning:** Allows fine-tuning of servo orientation and height for optimal lifter mechanism operation.
- **Material:** Recommended to print in PETG or ABS for strength, durability, and heat resistance.
- **Mounting:** Attaches to the RoboSort frame using M3 screws and heat-set inserts for robust installation.

**Usage:**
- Position the servo motor into the mount and secure with screws.
- Route the servo cables through the provided channels to prevent interference with moving parts.
- Mount the assembly on the designated frame location for the lifter mechanism.
- Ensure proper alignment with the lifter coupling adapter for efficient power transmission.
- The mount supports the servo during continuous lifting and lowering operations.

**Section Reference:** See also the [3D Model Documentation](diagrams/3d_model_specification.md) for technical details and print settings.

---

### RoboSort Lifter Limit Switch Mount
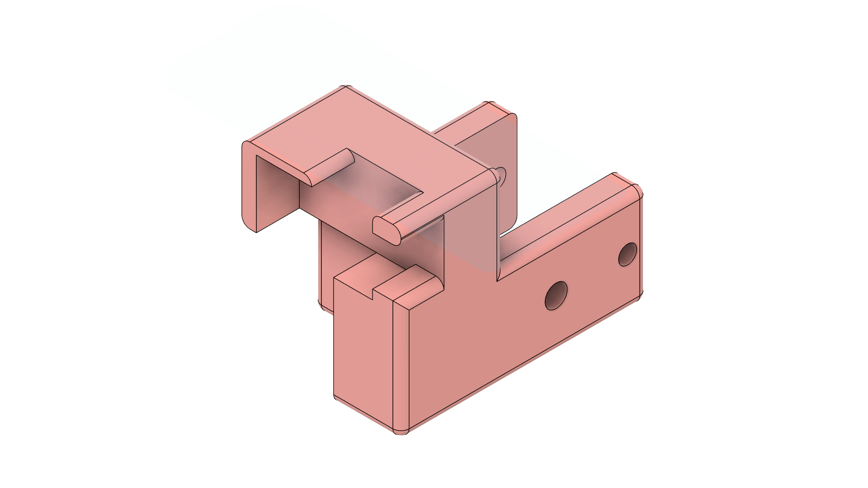
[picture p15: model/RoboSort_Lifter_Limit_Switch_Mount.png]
RoboSort Lifter Limit Switch Mount


**Description:**
The RoboSort Lifter Limit Switch Mount is a custom-designed 3D-printed bracket specifically engineered to securely hold and position limit switches for the lifter mechanism in the RoboSort platform. This mount provides precise positioning for end-stop sensors, ensuring accurate vertical movement control and safety limits for the lifting system during waste sorting operations. The mount works in conjunction with the lifter servo system to establish reference positions and prevent over-travel of the vertical mechanism.

**Key Features:**
- **Precision Alignment:** Designed with exact tolerances for accurate limit switch positioning and activation.
- **Secure Mounting:** Includes mounting holes for M3 screws and heat-set inserts for robust attachment to the lifter assembly.
- **Adjustable Switch Position:** Allows fine-tuning of limit switch placement for optimal activation timing.
- **Cable Management:** Integrated channels or clips for organizing limit switch wiring and preventing cable strain.
- **Durable Construction:** Recommended to print in PETG or ABS for impact resistance and dimensional stability.
- **Modular Design:** Easy to install and maintain as part of the lifter safety system.
- **Homing Capability:** Enables automatic lifter positioning and reference point establishment.

**Usage:**
- Mount the limit switch into the bracket and secure with appropriate hardware.
- Position the mount at the desired end-stop locations on the lifter mechanism (top and bottom limits).
- Adjust switch position to trigger at the correct vertical travel boundaries.
- Connect the limit switches to the Arduino for position feedback and safety limits.
- Test the limit switches to verify reliable activation during full lifter travel range.
- The mount provides position feedback for automated lifter control and safety protection.

**Section Reference:** See also the [3D Model Documentation](diagrams/3d_model_specification.md) for technical details and print settings.

---

### RoboSort Gripper
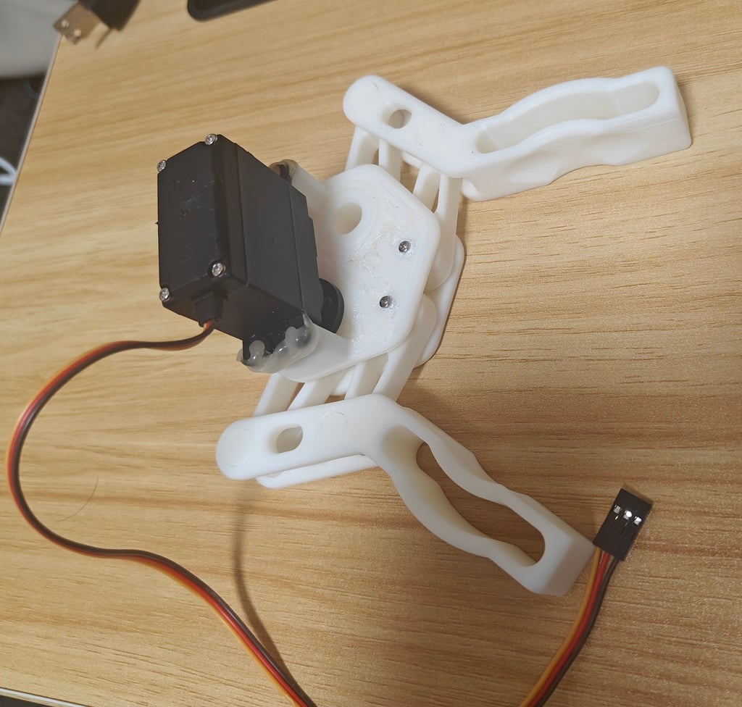
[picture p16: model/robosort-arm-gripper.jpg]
RoboSort Gripper


**Description:**
The RoboSort Gripper is a custom-designed robotic gripper specifically engineered for handling and manipulating waste materials in the RoboSort system. This gripper provides precise and reliable grasping capabilities for paper and plastic items during the automated sorting process. The model is sourced from Thingiverse (https://www.thingiverse.com/thing:6782186) and has been integrated into the RoboSort platform for optimal performance.

**Key Features:**
- **Precision Gripping:** Designed for secure handling of various waste materials without damage.
- **Robotic Arm Integration:** Compatible with the 5-DOF robotic arm for coordinated material transfer.
- **Lightweight Construction:** Optimized design to minimize load on servo motors during operation.
- **Adjustable Grip:** Allows for different grip strengths based on material type and size.
- **Durable Materials:** Recommended to print in PETG or ABS for strength and wear resistance.
- **Modular Design:** Easy to assemble and maintain as part of the robotic system.

**Usage:**
- Install the gripper onto the robotic arm's end effector.
- Calibrate grip strength for different material types (paper vs plastic).
- Use in conjunction with the vision system for targeted material pickup.
- Ensure proper alignment with the plate and bin mechanisms for smooth sorting operations.

**Section Reference:** See also the [3D Model Documentation](diagrams/3d_model_specification.md) for technical details and print settings.

---

### RoboSort Arm Gripper Rotator Mount
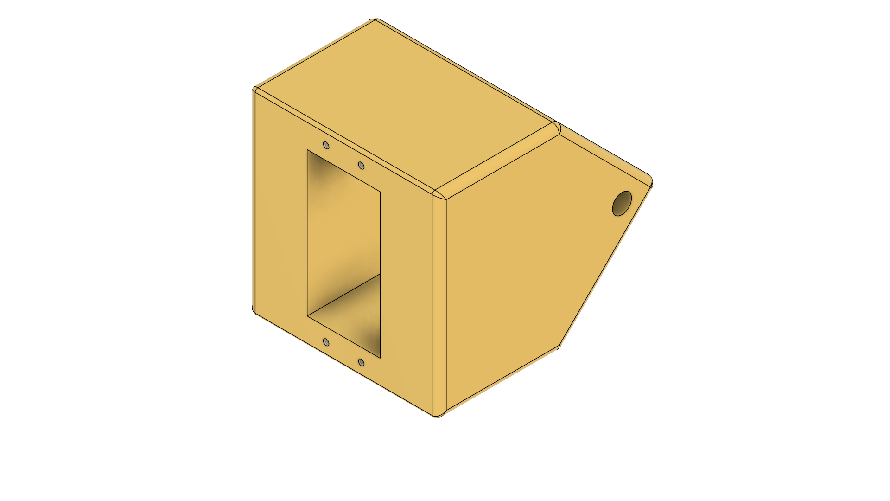
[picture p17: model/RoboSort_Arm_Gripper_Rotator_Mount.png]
RoboSort Arm Gripper Rotator Mount


**Description:**
The RoboSort Arm Gripper Rotator Mount is a custom-designed 3D-printed bracket specifically engineered to securely hold and position a servo motor for gripper rotation in the RoboSort robotic arm system. This mount provides precise alignment and stable support for rotational control of the gripper, enabling the robotic arm to orient waste materials at optimal angles during the sorting process. The mount works in conjunction with the gripper system to provide enhanced manipulation capabilities for accurate material placement.

**Key Features:**
- **Precision Alignment:** Designed with exact tolerances to match standard servo motor dimensions for secure, wobble-free mounting.
- **Rotational Control:** Enables 360° gripper rotation for optimal material orientation during sorting.
- **Vibration Dampening:** Includes features to minimize servo vibration during operation, improving control accuracy.
- **Cable Management:** Integrated channels or clips for organizing servo power and signal cables.
- **Adjustable Positioning:** Allows fine-tuning of servo orientation for optimal gripper rotation performance.
- **Material:** Recommended to print in PETG or ABS for strength, durability, and heat resistance.
- **Mounting:** Attaches to the robotic arm structure using M3 screws and heat-set inserts for robust installation.

**Usage:**
- Position the servo motor into the mount and secure with screws.
- Route the servo cables through the provided channels to prevent interference with moving parts.
- Mount the assembly on the designated robotic arm location for gripper rotation control.
- Ensure proper alignment with the gripper mechanism for efficient rotational power transmission.
- Calibrate the servo angles for optimal material orientation during sorting operations.
- The mount supports the servo during continuous gripper rotation operations.

**Section Reference:** See also the [3D Model Documentation](diagrams/3d_model_specification.md) for technical details and print settings.

---

### RoboSort Arm Gripper Servo Hand Mount
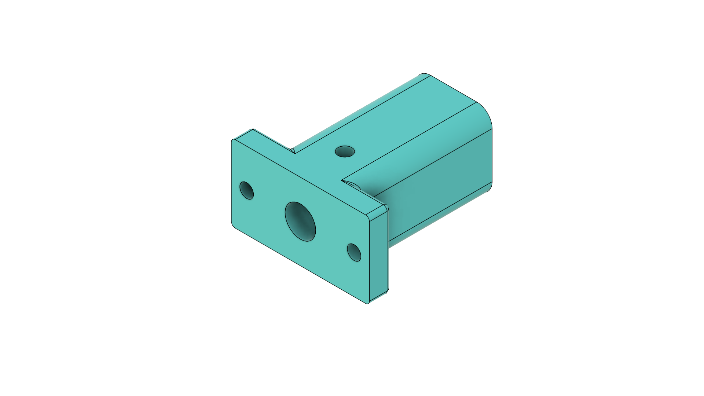
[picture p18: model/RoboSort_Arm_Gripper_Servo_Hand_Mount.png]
RoboSort Arm Gripper Servo Hand Mount


**Description:**
The RoboSort Arm Gripper Servo Hand Mount is a custom-designed 3D-printed coupling component specifically engineered to connect the gripper hand mechanism to the servo shaft of the gripper rotator mount servo in the RoboSort robotic arm system. This mount provides a secure interface between the rotating servo output and the gripper hand assembly, enabling coordinated rotational and grasping movements during waste material handling. The mount works in conjunction with both the gripper rotator servo and the gripper hand mechanism to provide precise multi-axis manipulation capabilities for accurate material pickup and placement.

**Key Features:**
- **Servo Shaft Coupling:** Designed with exact tolerances to securely attach to the gripper rotator servo output shaft.
- **Rotational Interface:** Provides stable connection between the rotating servo and gripper hand assembly.
- **Vibration Dampening:** Includes features to minimize vibration transmission during operation, improving control accuracy.
- **Cable Management:** Integrated channels or clips for organizing servo power and signal cables.
- **Adjustable Positioning:** Allows fine-tuning of gripper hand orientation relative to the servo shaft.
- **Material:** Recommended to print in PETG or ABS for strength, durability, and heat resistance.
- **Mounting:** Attaches to the gripper rotator servo shaft using set screws or press-fit connections for robust installation.

**Usage:**
- Attach the mount to the output shaft of the gripper rotator servo using set screws or press-fit connection.
- Route the servo cables through the provided channels to prevent interference with moving parts.
- Mount the gripper hand assembly to the mount for coordinated rotational movement.
- Ensure proper alignment between the servo shaft and gripper hand for efficient power transmission.
- Calibrate the servo angles for optimal gripper rotation and hand positioning during material handling.
- The mount enables synchronized rotational and grasping movements during continuous operation cycles.

**Section Reference:** See also the [3D Model Documentation](diagrams/3d_model_specification.md) for technical details and print settings.

---

### RoboSort Arm Gripper Hand Extension
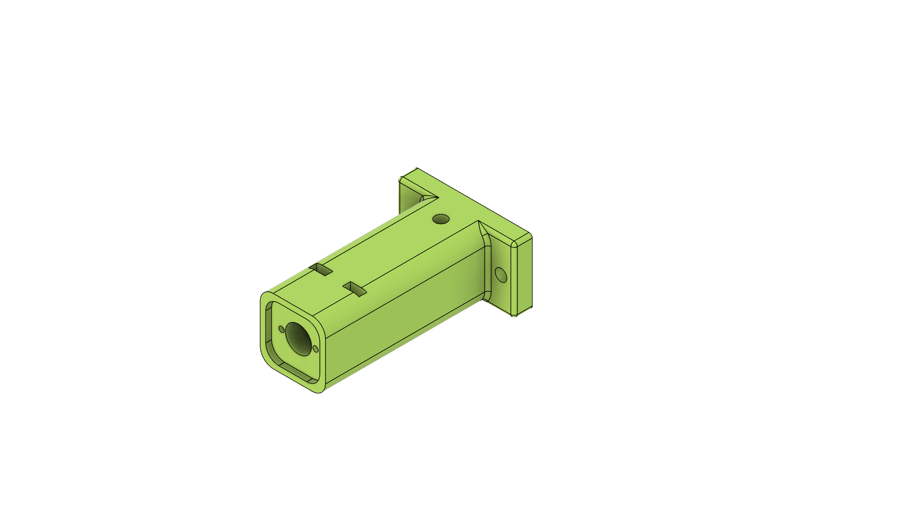
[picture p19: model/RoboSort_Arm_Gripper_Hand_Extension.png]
RoboSort Arm Gripper Hand Extension


**Description:**
The RoboSort Arm Gripper Hand Extension is a custom-designed 3D-printed extension component specifically engineered to extend the reach and positioning of the gripper hand mechanism in the RoboSort robotic arm system. This extension provides additional length and flexibility for the gripper assembly, enabling better access to waste materials in various positions during the sorting process. The extension works in conjunction with the gripper hand mount and rotator system to provide enhanced manipulation capabilities for accurate material pickup and placement.

**Key Features:**
- **Extended Reach:** Provides additional length to improve gripper access to materials in different positions.
- **Flexible Positioning:** Allows for better alignment and orientation of the gripper during sorting operations.
- **Lightweight Design:** Optimized weight distribution to minimize load on servo motors during operation.
- **Secure Connection:** Designed with precise tolerances for stable attachment to the gripper hand assembly.
- **Modular Design:** Easy to attach and detach as needed for different sorting requirements.
- **Material:** Recommended to print in PETG or ABS for strength, durability, and flexibility.
- **Mounting:** Attaches to the gripper hand mount using screws or snap-fit connections for quick installation.

**Usage:**
- Attach the extension to the gripper hand mount using the provided connection points.
- Ensure proper alignment with the gripper fingers for optimal material handling.
- Position the extension to extend the gripper's reach for materials in hard-to-access locations.
- Test the extended range during calibration to ensure proper servo control and positioning.
- Use the extension when additional reach is needed for specific sorting scenarios.
- The extension enhances the gripper's versatility during continuous sorting operations.

**Section Reference:** See also the [3D Model Documentation](diagrams/3d_model_specification.md) for technical details and print settings.

---

### RoboSort Bin Entrance Safety Mount
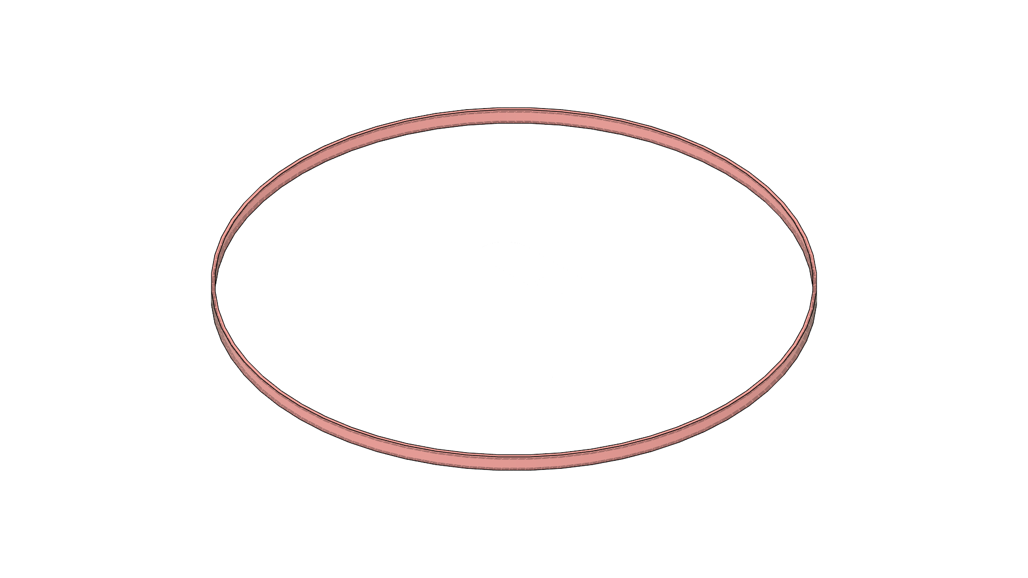
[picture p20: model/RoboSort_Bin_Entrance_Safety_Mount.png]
RoboSort Bin Entrance Safety Mount


**Description:**
The RoboSort Bin Entrance Safety Mount is a custom-designed 3D-printed safety component specifically engineered to protect users from sharp edges at the bin entrance. Since the material bins are constructed from plain sheet metal with potentially hazardous sharp edges, this mount provides a protective barrier and smooth entry surface to prevent cuts and injuries during waste material insertion.

**Key Features:**
- **Safety Protection:** Designed with rounded edges and protective padding to eliminate sharp contact points.
- **Secure Mounting:** Includes mounting holes for M3 screws and heat-set inserts for robust attachment to the bin entrance.
- **Smooth Surface:** Provides a gentle, curved entry guide for safe material insertion.
- **Durable Construction:** Recommended to print in PETG or ABS for strength and impact resistance.
- **Universal Fit:** Compatible with standard bin designs and can be adapted for different bin sizes.
- **Easy Installation:** Modular design allows for quick assembly and maintenance.

**Usage:**
- Install the safety mount at the entrance of each sorting bin.
- Ensure the protective surface is positioned to cover all sharp edges.
- Regularly inspect for wear and replace as needed to maintain safety standards.
- Works in conjunction with the bin rotation system for complete waste segregation safety.

**Section Reference:** See also the [3D Model Documentation](diagrams/3d_model_specification.md) for technical details and print settings.

---

### RoboSort Bin Stepper Mount
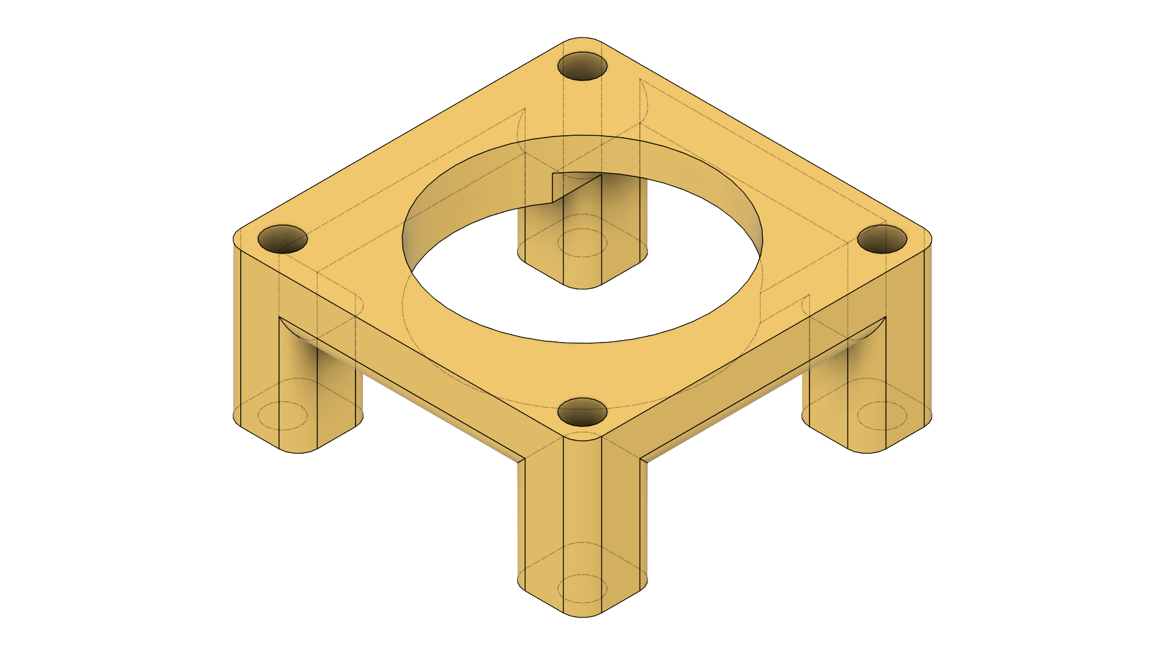
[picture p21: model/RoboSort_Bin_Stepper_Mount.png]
RoboSort Bin Stepper Mount


**Description:**
The RoboSort Bin Stepper Mount is a custom-designed 3D-printed bracket specifically engineered to securely hold and position the stepper motor responsible for bin rotation in the RoboSort platform. This mount provides precise alignment and stable support for the stepper motor, ensuring accurate and reliable rotational movement of the sorting bins during waste segregation operations.

**Key Features:**
- **Precision Alignment:** Designed with exact tolerances to match standard NEMA stepper motor dimensions for secure, wobble-free mounting.
- **Vibration Dampening:** Includes features to minimize motor vibration during operation, improving control accuracy.
- **Cable Management:** Integrated channels or clips for organizing stepper motor power and signal cables.
- **Adjustable Positioning:** Allows fine-tuning of motor orientation for optimal bin rotation performance.
- **Material:** Recommended to print in PETG or ABS for strength, durability, and heat resistance.
- **Mounting:** Attaches to the RoboSort frame using M3 screws and heat-set inserts for robust installation.

**Usage:**
- Position the stepper motor into the mount and secure with screws.
- Route the motor cables through the provided channels to prevent interference with moving parts.
- Mount the assembly on the designated frame location for the bin rotation mechanism.
- Ensure proper alignment with the bin gear system for efficient power transmission.
- The mount supports the stepper motor during continuous bin rotation operations.

**Section Reference:** See also the [3D Model Documentation](diagrams/3d_model_specification.md) for technical details and print settings.

---

### RoboSort Bin Tensioner Mount
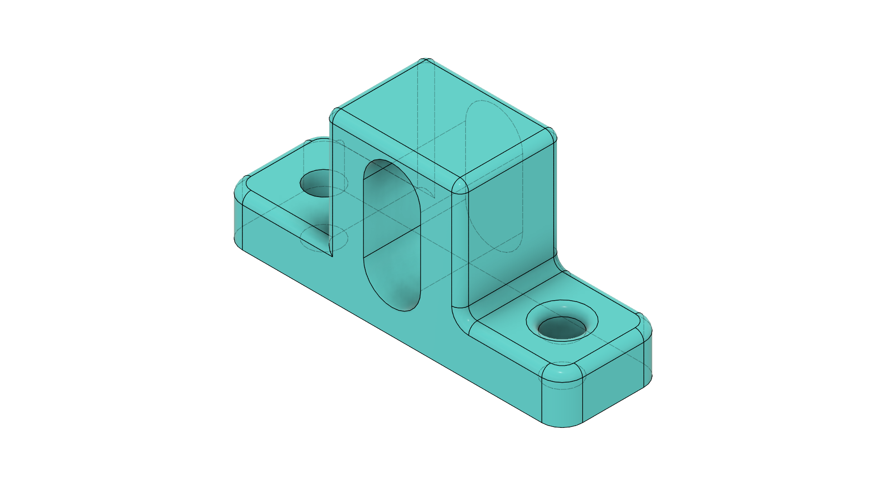
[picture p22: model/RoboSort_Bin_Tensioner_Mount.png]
RoboSort Bin Tensioner Mount


**Description:**
The RoboSort Bin Tensioner Mount is a custom-designed 3D-printed bracket specifically engineered to securely hold and position the belt tensioner for the bin stepper motor system in the RoboSort platform. This mount provides proper tensioning of the drive belt, ensuring smooth and reliable power transmission from the stepper motor to the bin rotation mechanism during waste segregation operations.

**Key Features:**
- **Belt Tensioning:** Designed to maintain optimal belt tension for efficient power transfer.
- **Secure Mounting:** Includes mounting holes for M3 screws and heat-set inserts for robust attachment.
- **Adjustable Tension:** Allows fine-tuning of belt tension for optimal performance and longevity.
- **Vibration Dampening:** Features designed to minimize belt vibration during operation.
- **Modular Design:** Allows for easy assembly and maintenance of the bin drive system.
- **Material:** Recommended to print in PETG or ABS for strength and durability.
- **Mounting:** Attaches to the RoboSort frame using standard fasteners.

**Usage:**
- Install the tensioner into the mount and secure with appropriate hardware.
- Position the mount to achieve proper belt tension for the bin stepper system.
- Adjust tension as needed to ensure smooth bin rotation without slippage.
- Regularly inspect belt condition and tension for optimal performance.
- The mount maintains belt tension during continuous sorting operations.

**Section Reference:** See also the [3D Model Documentation](diagrams/3d_model_specification.md) for technical details and print settings.

---

### RoboSort Bin Tensioner Pulley Mount
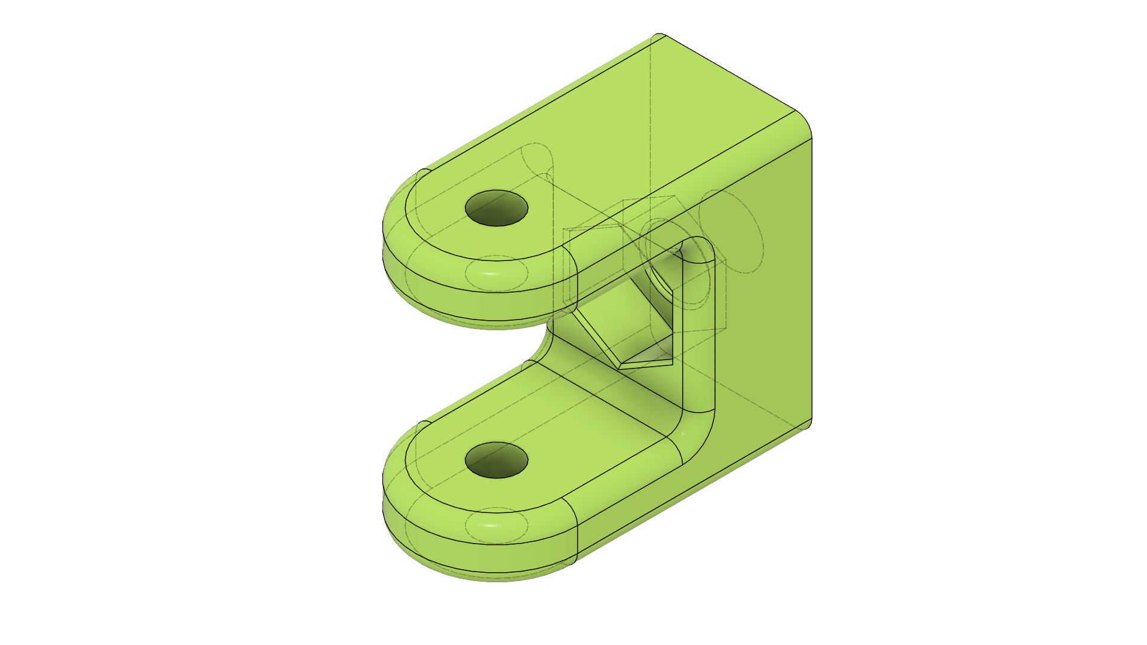
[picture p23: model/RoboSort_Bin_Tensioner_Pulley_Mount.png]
RoboSort Bin Tensioner Pulley Mount


**Description:**
The RoboSort Bin Tensioner Pulley Mount is a custom-designed 3D-printed bracket specifically engineered to securely hold the pulley bearing that tensions the drive belt in the bin stepper motor system. This mount works in conjunction with the Bin Tensioner Mount, connected via an 8mm bolt (55mm length), to provide adjustable belt tensioning for smooth and reliable power transmission during waste segregation operations.

**Key Features:**
- **Pulley Bearing Support:** Designed to securely hold the pulley bearing for optimal belt contact.
- **Tensioner Integration:** Connects to the Bin Tensioner Mount using an 8mm bolt (55mm length) for adjustable tension.
- **Precision Alignment:** Ensures proper pulley positioning for efficient belt tracking and tension.
- **Secure Mounting:** Includes mounting holes for M3 screws and heat-set inserts for robust attachment.
- **Bearing Compatibility:** Designed to accommodate standard pulley bearings for belt drive systems.
- **Material:** Recommended to print in PETG or ABS for strength and wear resistance.
- **Modular Design:** Allows for easy assembly and tension adjustment.

**Usage:**
- Install the pulley bearing into the mount according to specifications.
- Connect to the Bin Tensioner Mount using the 8mm bolt (55mm length).
- Position the assembly to achieve proper belt tension and alignment.
- Adjust the tensioner position as needed to maintain optimal belt performance.
- Regularly inspect bearing condition and belt wear for maintenance.
- The mount ensures consistent belt tension during continuous bin rotation operations.

**Section Reference:** See also the [3D Model Documentation](diagrams/3d_model_specification.md) for technical details and print settings.

---

### RoboSort Bin Limit Switch Trigger
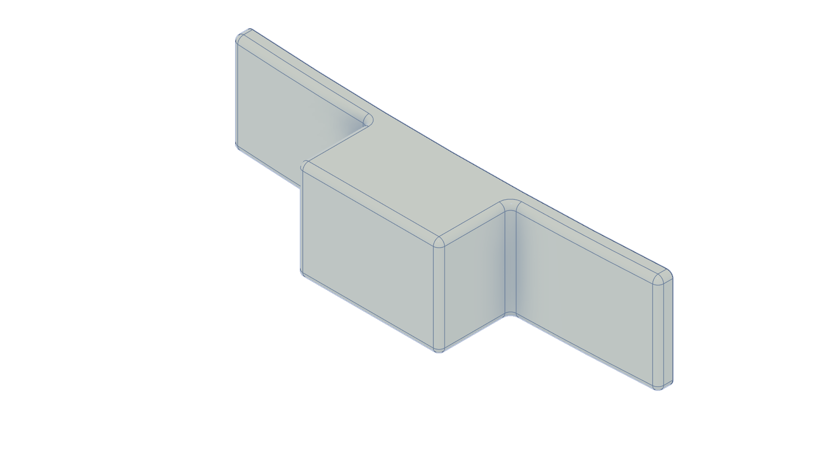
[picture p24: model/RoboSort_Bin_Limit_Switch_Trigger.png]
RoboSort Bin Limit Switch Trigger


**Description:**
The RoboSort Bin Limit Switch Trigger is a custom-designed 3D-printed mechanical component specifically engineered to activate limit switches during bin rotation in the RoboSort platform. This trigger provides precise position detection and homing capabilities for the bin stepper motor system, ensuring accurate and safe rotational movement during waste segregation operations. The trigger works in conjunction with limit switches to establish reference positions and prevent over-rotation of the sorting bins.

**Key Features:**
- **Precision Activation:** Designed with exact geometry to reliably trigger limit switches at specific bin positions.
- **Secure Mounting:** Includes mounting holes for M3 screws and heat-set inserts for robust attachment to the bin assembly.
- **Adjustable Positioning:** Allows fine-tuning of trigger placement for optimal switch activation timing.
- **Durable Construction:** Recommended to print in PETG or ABS for impact resistance and dimensional stability.
- **Modular Design:** Easy to install and replace as part of the bin rotation safety system.
- **Homing Functionality:** Enables automatic bin positioning and reference point establishment.
- **Safety Integration:** Works with limit switches to prevent mechanical damage from over-rotation.

**Usage:**
- Mount the trigger on the rotating bin assembly at the desired reference position.
- Position the corresponding limit switch to be activated by the trigger during bin rotation.
- Adjust trigger placement to ensure switch activation occurs at the correct bin orientation.
- Connect the limit switch to the Arduino for position feedback and homing operations.
- Test the trigger mechanism to verify reliable switch activation during full bin rotation cycles.
- The trigger provides position feedback for automated bin positioning and safety limits.

**Section Reference:** See also the [3D Model Documentation](diagrams/3d_model_specification.md) for technical details and print settings.

---

## Project Structure
```
robo-sort/
├── LICENSE
├── README.md
├── .gitignore                      # Git ignore patterns for build files and 3D models
├── diagram/                        # Circuit diagrams and schematics
│   ├── Wiring.fzz                  # Fritzing wiring diagram (editable)
│   └── Wiring.png                  # Wiring diagram image
├── diagrams/                       # Additional system diagrams
├── ml/                            # Machine learning training data
│   └── train/
│       ├── args.yaml              # Training configuration
│       ├── results.csv            # Training results
│       └── weights/               # Trained model weights
├── model/                         # 3D models and images (not in git)
│   ├── *.gcode                    # CNC machining files
│   ├── *.stl                      # 3D printable models
│   └── *.jpg                      # Hardware photos
└── source/
    ├── arduino/
    │   └── RoboSort/
    │       ├── RoboSort.ino              # Main firmware with integrated control
    │       ├── SERVO_CONFIG.h            # Servo driver header
    │       ├── SERVO_CONFIG.cpp          # Servo driver implementation
    │       ├── TB6600.h                  # TB6600 stepper motor driver header
    │       ├── TB6600.cpp                # TB6600 stepper motor driver implementation
    │       ├── ULTRASONIC_CONFIG.h       # Ultrasonic sensor header
    │       └── ULTRASONIC_CONFIG.cpp     # Ultrasonic sensor implementation
    └── rpi/
        ├── reference/                     # Legacy Python implementation
        │   ├── RoboSort.py               # Original CLI application
        │   ├── serial_config.py          # Serial communication module
        │   ├── yolo_detect.py            # AI Vision System
        │   └── requirements.txt          # Python dependencies
        ├── RoboSort/                     # Current Python implementation
        │   ├── RoboSort.py               # Main application with CLI interface
        │   ├── serial_config.py          # Serial communication module
        │   ├── yolo_detect.py            # AI Vision System (duplicate for easy access)
        │   └── requirements.txt          # Python dependencies
        ├── ros2-robosort/                # ROS2 Jazzy workspace
        │   ├── src/
        │   │   ├── ldlidar_stl_ros2/     # LD06 LiDAR driver
        │   │   ├── robosort_control/     # Main control package
        │   │   │   ├── robosort_control/
        │   │   │   │   ├── initial_odom_publisher.py  # Initial odometry for RViz
        │   │   │   │   ├── lidar_tf_publisher.py      # LiDAR TF broadcaster
        │   │   │   │   ├── motor_controller.py        # DC motor control
        │   │   │   │   ├── obstacle_avoidance.py      # Navigation safety
        │   │   │   │   ├── tf_broadcaster.py          # Coordinate frame management
        │   │   │   │   └── __init__.py
        │   │   │   ├── config/
        │   │   │   │   ├── nav2_params.yaml           # Nav2 navigation parameters
        │   │   │   │   ├── params.yaml                # General parameters
        │   │   │   │   ├── rf2o_params.yaml           # RF2O odometry parameters
        │   │   │   │   └── robosort.rviz              # RViz configuration
        │   │   │   └── launch/
        │   │   │       ├── nav2_no_docking.launch.py  # Nav2 launch without docking
        │   │   │       └── robosort.launch.py         # Main system launch
        │   │   ├── robosort_description/  # URDF robot description
        │   │   ├── robosort_interfaces/   # ROS2 service/message definitions
        │   │   ├── robosort_sensors/      # Sensor integration
        │   │   └── robosort_vision/       # YOLO vision processing
        │   ├── config/
        │   │   └── mapper_params_online_async.yaml  # SLAM parameters
        │   ├── start_robosort.sh         # Quick start script
        │   ├── verify_rf2o_setup.sh      # RF2O diagnostics script
        │   ├── my_map.pgm                # SLAM-generated map
        │   └── my_map.yaml               # Map metadata
        ├── test/                         # Testing utilities
        └── yolo/                         # YOLO model management
            ├── my_model.pt              # Trained YOLO model
            ├── my_model.torchscript     # TorchScript export
            ├── requirements.txt         # YOLO dependencies
            ├── yolo_detect.py           # YOLO detection script
            └── my_model_ncnn_model/     # NCNN optimized model
```

## AI Vision System Configuration

### YOLO Model Training
For optimal waste classification performance, train a custom YOLO model:

1. **Collect Dataset**: Gather images of paper and plastic waste materials
2. **Label Images**: Use tools like LabelImg or Roboflow to annotate objects
3. **Train Model**: Use Ultralytics YOLOv8 for training:
   ```bash
   pip install ultralytics
   yolo train data=waste_dataset.yaml model=yolov8n.pt epochs=100
   ```
4. **Export Model**: Convert to deployment format:
   ```bash
   yolo export model=runs/detect/train/weights/best.pt format=onnx
   ```

### LIDAR Sensor Calibration
- **LD06**: No calibration needed, factory calibrated

### Performance Optimization
- Use Raspberry Pi 4B+ or higher for best AI performance
- Enable GPU acceleration if available (NVIDIA Jetson)
- Adjust confidence threshold based on lighting conditions
- Use appropriate camera resolution for your use case

#### Technical Specifications
- **Chip**: NXP PCA9685 PWM controller
- **Resolution**: 12-bit (4096 steps)
- **PWM Frequency**: Adjustable from ~40Hz to ~1600Hz (typically 50Hz for servos)
- **Channels**: 16 independent PWM outputs
- **Interface**: I2C (uses only 2 pins: SDA and SCL)
- **Default I2C Address**: 0x40 (changeable via solder jumpers A0-A5)
- **Address Range**: 0x40 to 0x7F (allows up to 62 boards on one I2C bus)
- **Logic Level**: 5V tolerant I2C (works with 3.3V or 5V microcontrollers)
- **Power**: Separate power input for servos (up to 6V recommended)
- **Dimensions**: 2.5" x 1" x 0.1" (62.5mm x 25.4mm x 3mm)

#### Key Features
- **Free-Running PWM**: Built-in clock means no continuous signal needed from Arduino
- **Zero Processing Overhead**: Runs independently after initial setup
- **Chainable**: Control up to 992 servos using 62 boards with only 2 pins
- **Output Protection**: 220Ω series resistors on all outputs
- **Reverse Polarity Protection**: Built-in on terminal block
- **Configurable Output**: Push-pull or open-drain mode

#### Wiring Guide
**I2C Connections (Required):**
- SDA → Arduino A4 (Uno/Nano) or Pin 20 (Mega)
- SCL → Arduino A5 (Uno/Nano) or Pin 21 (Mega)
- VCC → Arduino 5V
- GND → Arduino GND

**Servo Power (Required):**
- V+ → External power supply positive (4.8V - 6V for most servos)
- GND → External power supply ground (must share common ground with Arduino)
- Note: Do NOT power servos from Arduino's 5V pin (insufficient current)

**Servo Connections:**
- Connect servos to any of the 16 three-pin headers
- Each header provides: PWM signal, VCC, and GND
- Servos can be plugged directly into the board

#### Address Selection
By default, the board uses I2C address 0x40. To change the address:
- Solder bridge combinations of A0-A5 jumpers on the board
- Each jumper adds to the base address (0x40)
- Example: Bridging A0 sets address to 0x41

#### Library Installation
Install the Adafruit PWM Servo Driver library in Arduino IDE:
```
Tools > Manage Libraries > Search "Adafruit PWM Servo Driver" > Install
```

### Servo Calibration
Adjust the servo pulse width limits in `SERVO_CONFIG.cpp`:
```cpp
#define SERVO_MIN_PULSE  150  // Minimum pulse length (0°)
#define SERVO_MAX_PULSE  600  // Maximum pulse length (180°)
```

**Calibration Tips:**
- Standard servos typically use 150-600 pulse range (1ms-2ms)
- Fine-tune these values if servos don't reach full range or jitter at endpoints
- Test with serial commands before finalizing pulse values
- Some servos may require 120-600 or 150-650 ranges

### Servo Channel Mapping
Modify the servo channel assignments in the `ServoConfig` constructor to match your wiring configuration.

### Stepper Motor Pin Configuration
Configure stepper motor driver pin connections in `PINS.h` according to your wiring:
```cpp
#define STEPPER_STEP_PIN 3  // PUL+ connected to pin 3
#define STEPPER_DIR_PIN 4   // DIR+ connected to pin 4
#define STEPPER_ENA_PIN 5   // ENA+ connected to pin 5
```

### TB6600 Stepper Motor Driver Wiring Guide
The TB6600 stepper motor driver uses the following interface:

**Control Connections:**
- PUL+ → Arduino digital pin (pulse for each step)
- DIR+ → Arduino digital pin (direction control)
- ENA+ → Arduino digital pin (enable/disable driver, active low)

**Motor Connections:**
- Connect stepper motor coils to A1/A2/B1/B2 terminals
- Ensure proper coil pairing (check motor datasheet)

**Power Connections:**
- VMOT → Motor power supply (8-35V depending on driver)
- GND → Common ground with Arduino
- VDD → Logic power (3.3-5V from Arduino)

**Control Connections:**
- Connect Arduino digital pins to STEP, DIR, and EN inputs
- Optional microstepping pins for finer resolution control
- Connect Arduino GND to driver GND (common ground required)

**Safety Notes:**
- Use appropriate power supply voltage for your stepper motor specifications
- Add decoupling capacitors (10-100µF) across motor power terminals
- Ensure proper current limiting on the driver to prevent motor overheating
- Keep motor power wires short and twisted to reduce noise
- Use shielded cables for STEP and DIR signals if experiencing interference

## System Integration

### Complete RoboSort Workflow
1. **Material Detection**: YOLO vision system identifies waste materials in the workspace
2. **Distance Measurement**: LIDAR ensures safe robotic approach distance
3. **Sorting Decision**: Raspberry Pi processes detection results and makes sorting decisions
4. **Robotic Action**: Arduino receives commands to actuate stepper motors and servos
5. **Material Handling**: Robotic arm picks and places materials in appropriate bins
6. **Quality Control**: System logs all actions for performance monitoring

### Safety Features
- **Collision Avoidance**: LIDAR provides 360° obstacle detection
- **Emergency Stop**: Hardware and software emergency stop capabilities
- **Fault Detection**: Automatic detection of sensor failures
- **Safe Operating Zones**: Configurable safety boundaries for robotic movement

### Performance Metrics
- **Detection Accuracy**: YOLO confidence scores for material classification
- **Processing Speed**: Real-time FPS monitoring
- **Sorting Efficiency**: Success rate tracking and optimization
- **System Reliability**: Uptime monitoring and fault detection

## System Architecture & Workflow Diagrams

This section provides comprehensive visual documentation of the RoboSort system architecture, workflows, and component interactions using Mermaid diagrams.

### System Architecture Diagram

```mermaid
graph TB
    subgraph "High-Level Processing"
        RPI[Raspberry Pi 4B]
        AI[AI Vision System]
        YOLO[YOLO Detection Engine]
        DE[Decision Engine]
    end
    
    subgraph "Low-Level Control"
        ARD[Arduino Mega 2560]
        SERVO[Servo Controller]
        STEPPER[Stepper Driver A4988]
        SENSORS[Sensor Interface]
    end
    
    subgraph "Hardware Components"
        ARM[Robotic Arm 5-DOF]
        CAMERA[USB Camera]
        LIDAR[LD06 LIDAR Sensor]
        ULTRA[HC-SR04 Ultrasonic]
        POWER[12V Power Supply]
    end
    
    subgraph "User Interface"
        DISPLAY[Display Output]
        KEYBOARD[Keyboard Input]
        MONITOR[Serial Monitor]
    end
    
    RPI -->|Serial USB 9600bps| ARD
    AI --> YOLO
    YOLO -->|Classification| DE
    DE -->|Control Commands| RPI
    
    ARD -->|PWM Signals| SERVO
    ARD -->|STEP/DIR| STEPPER
    ARD -->|Read Data| SENSORS
    
    SERVO -->|Control| ARM
    STEPPER -->|Motor Control| ARM
    SENSORS -->|Distance| ULTRA
    SENSORS -->|360° Scan| LIDAR
    
    CAMERA -->|Video Stream| AI
    LIDAR -->|Distance Data| AI
    POWER -->|Power| ARM
    POWER -->|Power| ARD
    POWER -->|Power| RPI
    
    DISPLAY -->|Visual Output| RPI
    KEYBOARD -->|User Input| RPI
    MONITOR -->|Debug Output| ARD
```

### Main Processing Workflow

```mermaid
graph TD
    A[Start System] --> B[Initialize Components]
    B --> C[Setup Camera]
    B --> D[Setup Serial Connection]
    B --> E[Setup LIDAR Sensor]

    C --> F[Camera Ready]
    D --> G[Serial Connected]
    E --> H[LIDAR Ready]

    F --> I{Main Processing Loop}
    G --> I
    H --> I

    I --> J[Capture Frame]
    J --> K[Run YOLO Detection]
    K --> L[Process Results]
    L --> M[Get LIDAR Data]
    M --> N[Fuse Sensor Data]
    N --> O{Material Detected?}

    O -->|Yes| P[Classify Material]
    O -->|No| Q[Continue Monitoring]

    P --> R{Classification}
    R -->|Paper| S[Send Paper Command]
    R -->|Plastic| T[Send Plastic Command]
    R -->|Other| U[Send Other Command]

    S --> V[Execute Robotic Action]
    T --> V
    U --> V

    V --> W[Display Results]
    W --> X[Log Data]
    X --> Y{Continue?}
    Y -->|Yes| I
    Y -->|No| Z[Shutdown System]

    Q --> I
    Z --> AA[End]
```

### Serial Communication Sequence

```mermaid
sequenceDiagram
    participant R as Raspberry Pi
    participant A as Arduino Mega
    participant H as Hardware

    R->>A: Connect USB Serial (9600bps)
    A-->>R: Ready Signal
    R->>R: Initialize Camera
    R->>R: Initialize LIDAR
    R->>R: Load YOLO Model

    loop Main Processing Loop
        R->>R: Capture Frame
        R->>R: Run YOLO Inference
        R->>R: Read LIDAR Data
        R->>R: Fuse Detection Results

        alt Object Detected
            R->>R: Classify Material
            R->>A: Send Control Command (e.g., "S0 90\n")
            A->>A: Parse Command
            A->>H: Execute Hardware Action
            H-->>A: Action Complete
            A-->>R: Response ("OK\n")
        end
    end

    R->>R: Display Results
    R->>R: Check Exit Condition
```

### System State Transitions

```mermaid
stateDiagram-v2
    [*] --> Initialization
    Initialization --> CameraSetup
    Initialization --> SerialSetup
    Initialization --> LIDARSetup

    CameraSetup --> Ready: Camera OK
    SerialSetup --> Ready: Serial OK
    LIDARSetup --> Ready: LIDAR OK

    Ready --> Processing: All Systems Ready

    state Processing {
        [*] --> Detection
        Detection --> Classification: Run YOLO
        Classification --> Fusion: Get LIDAR Data
        Fusion --> Decision: Analyze Results
        Decision --> Action: Object Found
        Decision --> Monitoring: No Object
        Action --> Command: Generate Command
        Command --> Execution: Send to Arduino
        Execution --> Response: Hardware Action
        Response --> [*]
        Monitoring --> [*]
    }

    Processing --> Processing: Continue
    Processing --> Shutdown: Stop Command
    Shutdown --> [*]
```

### Power Distribution Network

```mermaid
graph TD
    PS[12V DC Power Supply<br/>3A 36W] --> F1[Fuse F1<br/>2A]
    F1 --> ARD[Arduino Mega 2560<br/>VIN 7-12V]
    ARD --> REG[5V Regulator<br/>LM7805]
    REG --> F2[Fuse F2<br/>2A]
    F2 --> SERVO[Servo Motors<br/>5× MG996R]
    F2 --> LIDAR[LD06 LIDAR<br/>5V 200mA]
    PS --> STEPPER[Stepper Driver<br/>A4988 12V]
    ARD --> ULTRA[HC-SR04<br/>5V 15mA]
    
    style PS fill:#f9f,stroke:#333,stroke-width:4px
    style ARD fill:#bbf,stroke:#333,stroke-width:2px
    style REG fill:#bfb,stroke:#333,stroke-width:2px
```

### Component Pin Configuration

```mermaid
graph LR
    subgraph "Arduino Mega 2560"
        P0[Pin 0-1<br/>Serial RX/TX]
        P3[Pin 3-7<br/>Servo PWM]
        P8[Pin 8-13<br/>Stepper Control]
        P16[Pin 16-17<br/>LIDAR Serial2]
        P20[Pin 20-21<br/>I2C SDA/SCL]
        P22[Pin 22-23<br/>Ultrasonic]
    end
    
    P0 -->|USB Serial| RPI[Raspberry Pi]
    P3 -->|PWM| S1[Base Servo]
    P3 -->|PWM| S2[Shoulder Servo]
    P3 -->|PWM| S3[Elbow Servo]
    P3 -->|PWM| S4[Wrist Servo]
    P3 -->|PWM| S5[Gripper Servo]
    P8 -->|STEP/DIR/EN| DRIVER[A4988 Driver]
    P16 -->|TX2/RX2| LD[LD06 LIDAR]
    P20 -->|I2C| PCA[PCA9685 PWM]
    P22 -->|TRIG/ECHO| US[HC-SR04]
```

### Robotic Arm Assembly Structure

```mermaid
graph TD
    BASE[Base Platform<br/>400×300×20mm<br/>PETG Material] --> ARM_BASE[Arm Base Segment<br/>Ø80mm×50mm<br/>MG996R Servo]
    ARM_BASE --> SHOULDER[Shoulder Segment<br/>60×40×100mm<br/>MG996R Servo<br/>0-180° Range]
    SHOULDER --> ELBOW[Elbow Segment<br/>50×35×100mm<br/>MG996R Servo<br/>0-180° Range]
    ELBOW --> WRIST[Wrist Segment<br/>40×30×50mm<br/>MG996R Servo<br/>0-180° Rotation]
    WRIST --> GRIPPER[Gripper Assembly<br/>60×40×30mm<br/>SG90 Servo<br/>0-50mm Opening]
    
    BASE --> ELECTRONICS[Electronics Bay<br/>RPI + Arduino + Power]
    BASE --> BINS[Waste Bins<br/>3×100×100mm<br/>Paper/Plastic/Other]
```

### Sensor Data Flow

```mermaid
graph LR
    subgraph "Input Sensors"
        CAM[USB Camera<br/>Video Stream]
        LID[LD06 LIDAR<br/>360° Distance]
        ULT[HC-SR04<br/>Ultrasonic Distance]
    end
    
    subgraph "Processing"
        YOLO[YOLO Model<br/>Object Detection]
        FUSION[Sensor Fusion<br/>Data Integration]
        DECISION[Decision Engine<br/>Classification]
    end
    
    subgraph "Output"
        CMD[Serial Commands]
        DISPLAY[Visual Display]
        LOG[Data Logging]
    end
    
    CAM --> YOLO
    YOLO --> FUSION
    LID --> FUSION
    ULT --> FUSION
    FUSION --> DECISION
    DECISION --> CMD
    DECISION --> DISPLAY
    DECISION --> LOG
```

### Stepper Motor Control Microstepping

```mermaid
graph TD
    A[Stepper Motor Control] --> B{Microstepping Mode}
    B -->|MS1=0,MS2=0,MS3=0| C[Full Step<br/>200 steps/rev]
    B -->|MS1=1,MS2=0,MS3=0| D[Half Step<br/>400 steps/rev]
    B -->|MS1=0,MS2=1,MS3=0| E[1/4 Step<br/>800 steps/rev]
    B -->|MS1=1,MS2=1,MS3=0| F[1/8 Step<br/>1600 steps/rev]
    B -->|MS1=1,MS2=1,MS3=1| G[1/16 Step<br/>3200 steps/rev]
    
    C --> H[Arduino Pin 8: STEP]
    D --> H
    E --> H
    F --> H
    G --> H
    H --> I[Arduino Pin 9: DIR]
    I --> J[Arduino Pin 10: ENABLE]
```

### Material Classification Decision Tree

```mermaid
graph TD
    START[Object Detected] --> YOLO{YOLO Classification}
    YOLO -->|Confidence > 0.8| PAPER{Paper?}
    YOLO -->|Confidence > 0.8| PLASTIC{Plastic?}
    YOLO -->|Confidence < 0.8| OTHER[Other Material]
    
    PAPER -->|Yes| P_DIST[Check Distance<br/>LIDAR]
    PLASTIC -->|Yes| PL_DIST[Check Distance<br/>LIDAR]
    
    P_DIST -->|< 30cm| P_GRAB[Position Arm<br/>Paper Bin]
    PL_DIST -->|< 30cm| PL_GRAB[Position Arm<br/>Plastic Bin]
    OTHER --> O_GRAB[Position Arm<br/>Other Bin]
    
    P_GRAB --> GRIP[Close Gripper]
    PL_GRAB --> GRIP
    O_GRAB --> GRIP
    
    GRIP --> MOVE[Move to Bin]
    MOVE --> RELEASE[Open Gripper]
    RELEASE --> RETURN[Return to Home]
    RETURN --> DONE[Complete]
```

### Error Handling & Recovery

```mermaid
graph TD
    START[Operation] --> CHECK{Error Detected?}
    CHECK -->|No| CONTINUE[Continue Operation]
    CHECK -->|Yes| TYPE{Error Type}
    
    TYPE -->|Serial Timeout| SERIAL[Reconnect Serial<br/>Reset Arduino]
    TYPE -->|Camera Failure| CAMERA[Reinitialize Camera<br/>Check USB]
    TYPE -->|Servo Error| SERVO[Recalibrate Servos<br/>Check Power]
    TYPE -->|LIDAR Error| LIDAR[Reset LIDAR<br/>Check Serial2]
    
    SERIAL --> RETRY{Retry Count}
    CAMERA --> RETRY
    SERVO --> RETRY
    LIDAR --> RETRY
    
    RETRY -->|< 3| START
    RETRY -->|>= 3| ALERT[Alert User<br/>Log Error]
    ALERT --> SAFE[Enter Safe Mode]
    SAFE --> MANUAL[Manual Intervention]
    
    CONTINUE --> START
```

### Assembly and Manufacturing Process

```mermaid
graph LR
    subgraph "Design Phase"
        CAD[CAD Design<br/>Fusion 360]
        REVIEW[Design Review<br/>Standards Check]
        APPROVE[Approval]
    end
    
    subgraph "Manufacturing"
        SLICE[Slice Models<br/>3D Printer]
        PRINT[Print Components<br/>PETG/ABS/PLA]
        QC[Quality Control<br/>Dimensional Check]
    end
    
    subgraph "Assembly"
        MECH[Mechanical Assembly<br/>Base + Arm]
        ELECT[Electronics Install<br/>RPI + Arduino]
        WIRE[Wiring & Cabling<br/>Power + Signals]
    end
    
    subgraph "Testing"
        FUNC[Functional Testing<br/>Components]
        INTEG[Integration Testing<br/>System]
        CALIB[Calibration<br/>Sensors + Servos]
    end
    
    CAD --> REVIEW
    REVIEW --> APPROVE
    APPROVE --> SLICE
    SLICE --> PRINT
    PRINT --> QC
    QC --> MECH
    MECH --> ELECT
    ELECT --> WIRE
    WIRE --> FUNC
    FUNC --> INTEG
    INTEG --> CALIB
    CALIB --> DEPLOY[Deployment]
```

### Key Specifications Summary

#### Hardware Components
- **Microcontrollers**: Raspberry Pi 4B + Arduino Mega 2560
- **Servos**: 5× MG996R (11kg·cm torque), 1× SG90 (1.8kg·cm)
- **Stepper Driver**: A4988 with microstepping (Full to 1/16)
- **Sensors**: USB Camera, LD06 LIDAR (360°), HC-SR04 Ultrasonic
- **Power**: 12V 3A DC supply with 5V regulation

#### Communication Protocols
- **Serial USB**: 9600 bps (RPi ↔ Arduino)
- **LIDAR Serial**: 230400 bps (Arduino Serial2 ↔ LD06)
- **I2C**: SDA/SCL for PWM driver expansion
- **PWM**: 50Hz servo control signals

#### Physical Specifications
- **Base Platform**: 400mm × 300mm × 20mm
- **Arm Reach**: 300mm radius
- **Payload Capacity**: 500g
- **Positioning Accuracy**: ±2mm
- **Total Weight**: ~2.5kg assembled

#### Printing Specifications
- **Materials**: PETG (base), ABS (arm), PLA+ (mounts)
- **Layer Height**: 0.2mm standard
- **Infill**: 20-40% depending on component
- **Tolerances**: ±0.1mm general, ±0.05mm critical fits

For detailed hardware assembly and system understanding, refer to the diagrams folder.

## ROS2 Integration & LiDAR Odometry

### ROS2 Workspace Overview

The RoboSort system includes a complete ROS2 Jazzy workspace with advanced features including YOLO vision, LiDAR integration, URDF robot modeling, and coordinated control.

**Location:** `source/rpi/ros2-robosort/`

**Key Packages:**
- **robosort_interfaces** - Custom ROS2 service definitions (SetServo, MoveRobotArm, RotateBin, GetDistance, ControlMotor)
- **robosort_vision** - YOLO detector, Arduino serial bridge, waste segregation controller
- **robosort_sensors** - LiDAR LD06 integration with 3D object localization
- **robosort_description** - URDF 5-DOF robot arm model for visualization and kinematics
- **robosort_control** - DC motor control, LiDAR odometry, and navigation nodes

### LiDAR Odometry with RF2O

RoboSort uses `rf2o_laser_odometry` for accurate odometry estimation from LiDAR scan matching instead of dead-reckoning. This significantly reduces drift during navigation.

#### What Changed
- **Before**: `tf_broadcaster` computed odometry from `cmd_vel` commands (dead-reckoning)
- **After**: `rf2o_laser_odometry` computes odometry by matching consecutive laser scans (ICP)

#### TF Tree Structure (Unchanged)
```
map
 └─ odom (from slam_toolbox: provides map->odom transform for drift correction)
     └─ base_footprint (from rf2o_laser_odometry: provides odom->base_footprint)
         ├─ lidar_link (from lidar_tf_publisher)
         └─ base_link (from robot_state_publisher via URDF)
             ├─ left_wheel_link
             ├─ right_wheel_link
             ├─ front_left_caster_link
             └─ right_caster_link
```

### ROS2 Installation & Setup

#### Prerequisites
```bash
# Install ROS2 Jazzy (if not already installed)
sudo apt update
sudo apt install ros-jazzy-desktop ros-jazzy-vision-msgs ros-jazzy-cv-bridge

# Install Python dependencies
pip install ultralytics opencv-python pyserial numpy
```

#### Build Workspace
```bash
cd ~/robo-sort/source/rpi/ros2-robosort
source /opt/ros/jazzy/setup.bash
colcon build --symlink-install
source install/setup.bash
```

### LiDAR Odometry Setup

#### Install RF2O Package
```bash
# For ROS 2 Jazzy
sudo apt update
sudo apt install ros-jazzy-rf2o-laser-odometry
```

#### RF2O Parameters (`config/rf2o_params.yaml`)
Key parameters you can tune:
- **Frequency**: `freq: 20.0` - How often odometry is computed (Hz)
- **Max Correspondence Distance**: `max_correspondence_dist: 0.3` - Maximum distance for point matching
- **Covariance**: `sigma_scan_xy` and `sigma_scan_angle` - Uncertainty estimates for Nav2

### Launch Commands

**Terminal 1: Main RoboSort System**
```bash
cd ~/robo-sort/source/rpi/ros2-robosort
source /opt/ros/jazzy/setup.bash
source install/setup.bash
ros2 launch robosort_control robosort.launch.py \
    arduino_port:=/dev/ttyUSB0 \
    lidar_port:=/dev/ttyUSB1 \
    use_rviz:=true \
    use_teleop:=true \
    use_nav2:=false
```

**Terminal 2: SLAM Mapping**
```bash
cd ~/robo-sort/source/rpi/ros2-robosort
source /opt/ros/jazzy/setup.bash
ros2 launch slam_toolbox online_async_launch.py \
    params_file:=$HOME/robo-sort/source/rpi/ros2-robosort/config/mapper_params_online_async.yaml
```

### Key ROS2 Topics & Services

#### Topics
```bash
/scan                           # Raw 360° LiDAR scan
/odom                           # Robot odometry (from RF2O)
/tf                             # Transform tree
/robosort/detections            # YOLO detected objects
/robosort/object_distance       # Distance to closest object
```

#### Services
```bash
ros2 service call /robosort/set_servo robosort_interfaces/srv/SetServo \
    "{servo_num: 0, angle: 90}"

ros2 service call /robosort/move_arm robosort_interfaces/srv/MoveRobotArm \
    "{joint_angles: [90.0, 45.0, 45.0, 90.0, 0.0]}"
```

### Quick Start Scripts

#### Automated Launch
```bash
cd ~/robo-sort/source/rpi/ros2-robosort
./start_robosort.sh
```

#### RF2O Diagnostics
```bash
cd ~/robo-sort/source/rpi/ros2-robosort
./verify_rf2o_setup.sh
```

### Troubleshooting ROS2 & LiDAR

#### LiDAR Communication Error
```bash
# Find LiDAR device
ls /dev/ttyUSB* /dev/ttyACM*

# Add user to dialout group
sudo usermod -a -G dialout $USER
newgrp dialout
```

#### RF2O Not Publishing Odometry
**Symptoms**: No `/odom` topic or TF warnings
**Solutions**:
1. Check LiDAR is publishing: `ros2 topic hz /scan`
2. Verify frame IDs match: `ros2 topic echo /scan --field header.frame_id`
3. Check RF2O logs: `ros2 node list` and look for errors

#### High Drift Still Present
**Symptoms**: Robot position drifts during movement
**Solutions**:
1. Increase scan matching frequency: Edit `rf2o_params.yaml`, set `freq: 30.0`
2. Reduce max correspondence distance: Set `max_correspondence_dist: 0.2`
3. Ensure LiDAR is mounted rigidly (no vibration)

## Development

### Adding New Features
1. For hardware control: Edit Arduino files in `source/arduino/RoboSort/`
2. For high-level logic: Edit Python files in `source/rpi/RoboSort/`
3. Test thoroughly using the serial command interface

### Debugging
- Use the Arduino Serial Monitor for low-level debugging
- Add Serial.println() statements in the Arduino code
- Use Python's print() or logging module for Raspberry Pi debugging

## Contributing
Contributions are welcome! Please follow these guidelines:
1. Fork the repository
2. Create a feature branch
3. Commit your changes with clear, descriptive messages
4. Push to your fork
5. Submit a pull request

## License
This project is licensed under the MIT License. See the LICENSE file for details.

## Contact

For questions, suggestions, or contributions, feel free to reach out:

- **Email**: quezon.province.pd@gmail.com
- **GitHub**: [github.com/qppd](https://github.com/qppd)
- **Portfolio**: [sajed-mendoza.onrender.com](https://sajed-mendoza.onrender.com)
- **Facebook**: [facebook.com/qppd.dev](https://facebook.com/qppd.dev)
- **Facebook Page**: [facebook.com/QUEZONPROVINCEDEVS](https://facebook.com/QUEZONPROVINCEDEVS)

```mermaid
graph TD
    A[Start] --> B[Display Banner]
    B --> C[Configure Serial Port]
    C --> D[Establish Connection with Arduino]
    D --> E{Connection Successful?}
    E -- No --> F[Display Error and Exit]
    E -- Yes --> G[Wait for Arduino Initialization]
    G --> H[Read Initial Messages from Arduino]
    H --> I[Display Command Menu]
    I --> J[User Selects Command]
    J --> K{Command Type}
    K -- Test Servos --> L[Test Servo Functionality]
    K -- Set Servo Angle --> M[Set Specific Servo Angle]
    K -- Test Motors --> N[Test Motor Functionality]
    K -- Control Motor --> O[Control Specific Motor]
    K -- Stop Motors --> P[Stop All Motors]
    K -- Test Ultrasonic --> Q[Test Ultrasonic Sensor]
    K -- Get Distance --> R[Get Distance Measurement]
    K -- Get Average Distance --> S[Get Average Distance]
    K -- Detect Object --> T[Detect Object with Threshold]
    K -- Custom Command --> U[Send Custom Command to Arduino]
    K -- Exit --> V[Exit Program]
    L --> I
    M --> I
    N --> I
    O --> I
    P --> I
    Q --> I
    R --> I
    S --> I
    T --> I
    U --> I
    V --> W[Disconnect and Clean Up]
    W --> X[End]
```

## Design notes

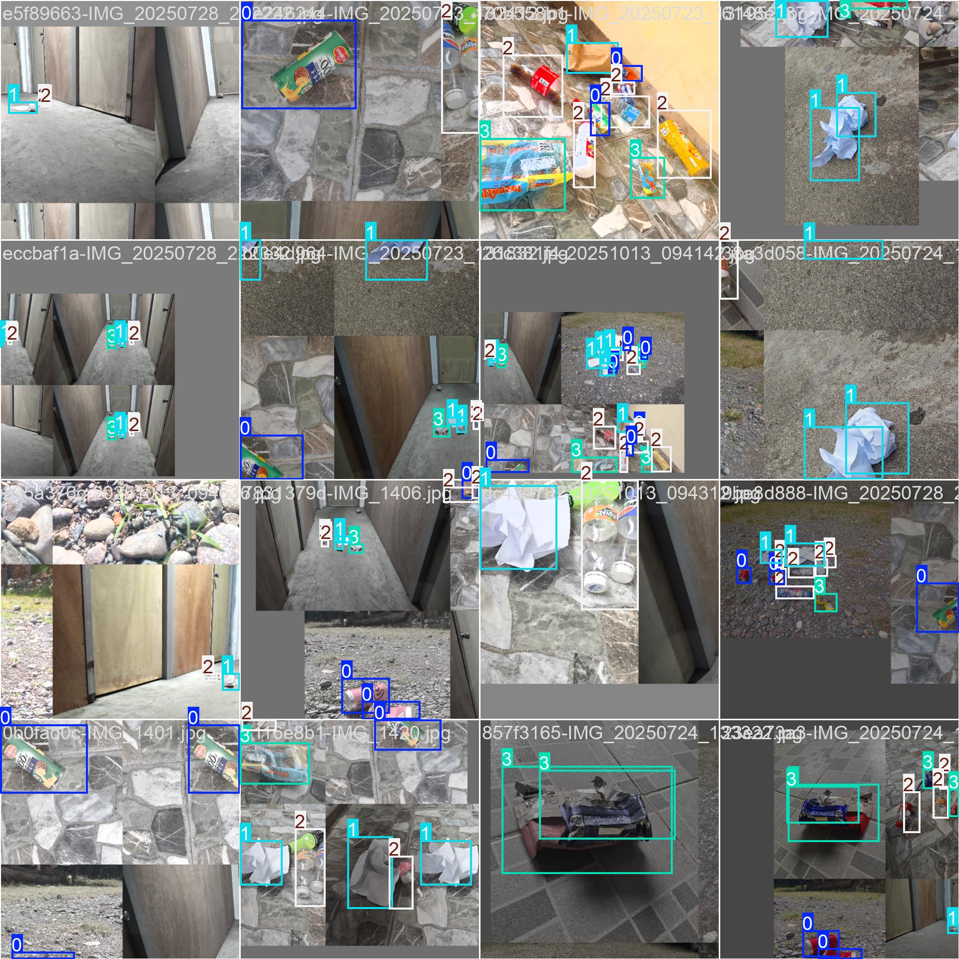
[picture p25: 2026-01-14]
ml/train/train_batch1.jpg

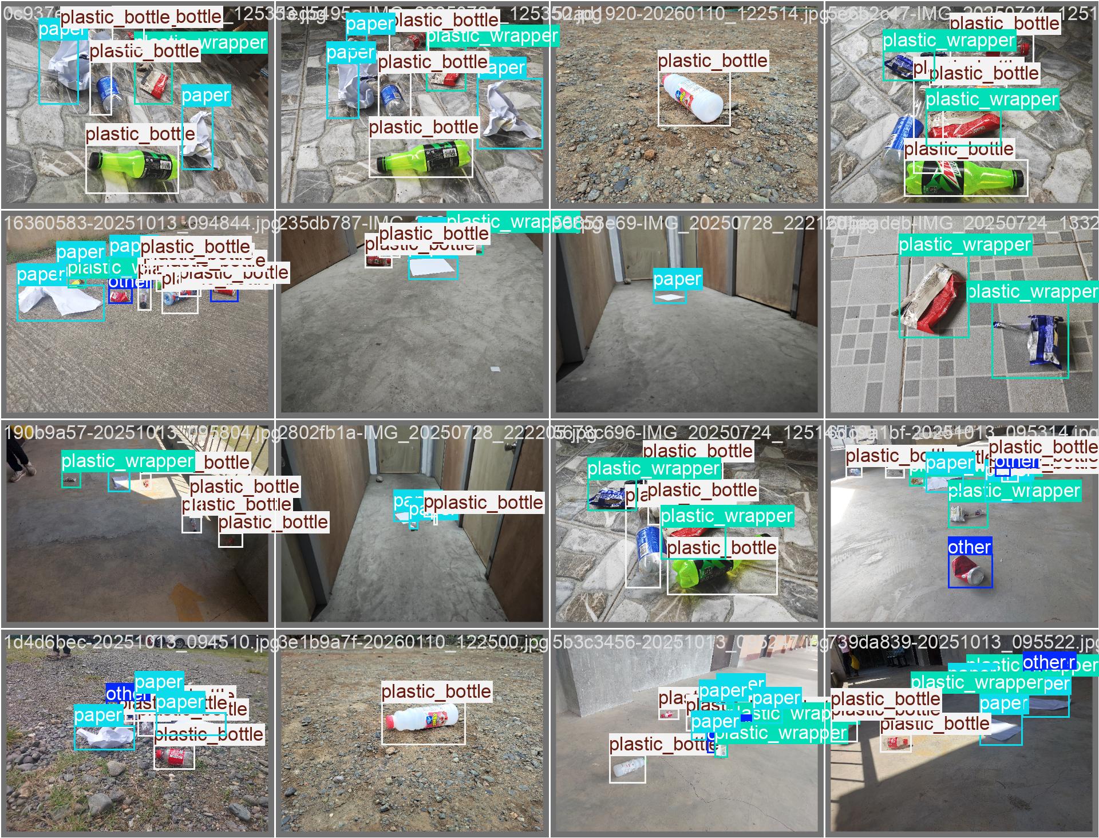
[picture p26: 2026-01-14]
ml/train/val_batch0_labels.jpg

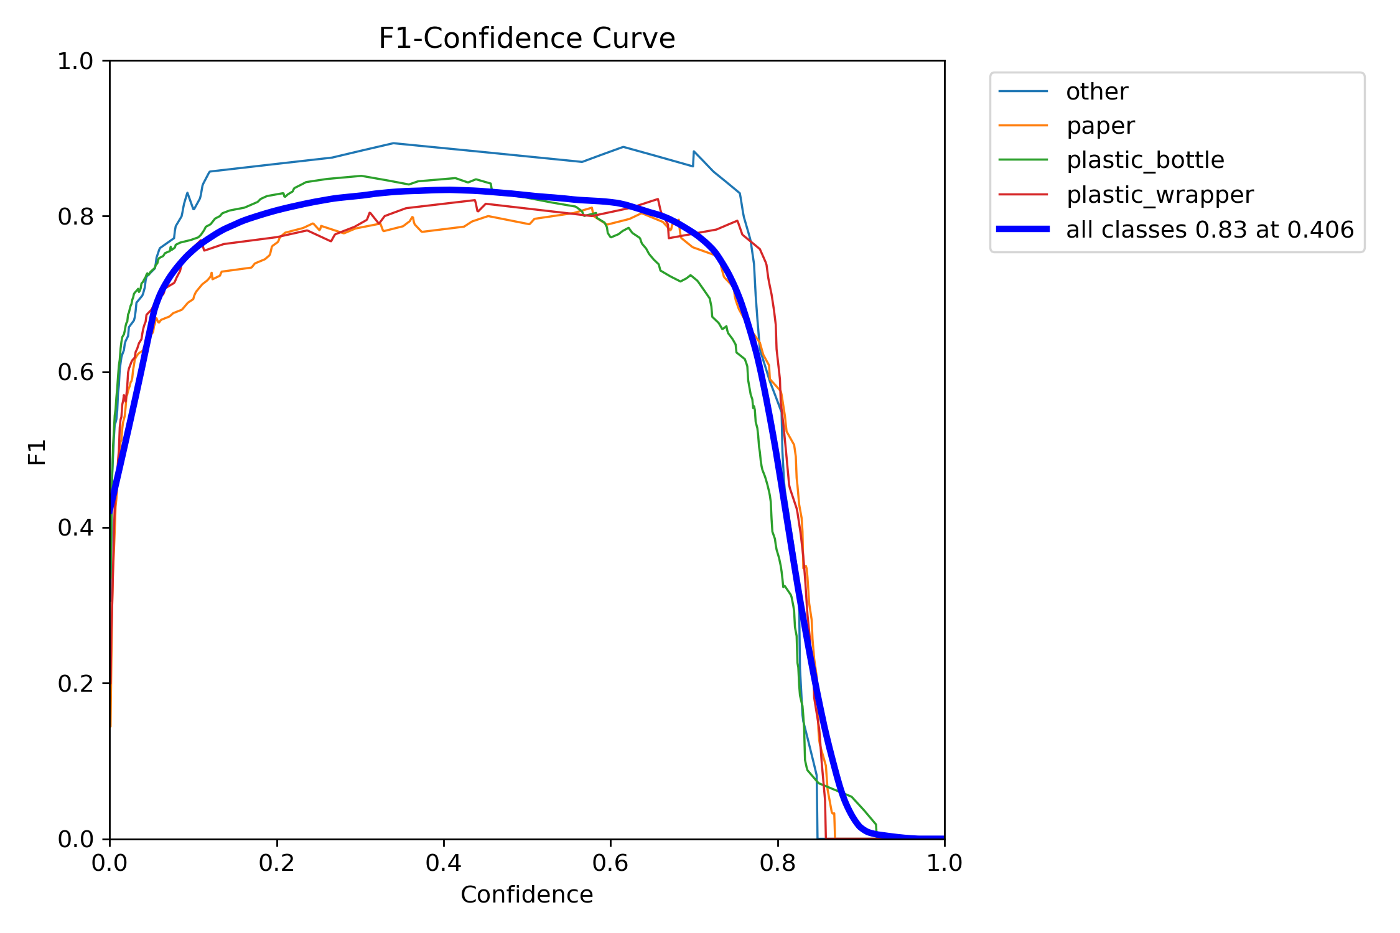
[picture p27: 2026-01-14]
ml/train/BoxF1_curve.png

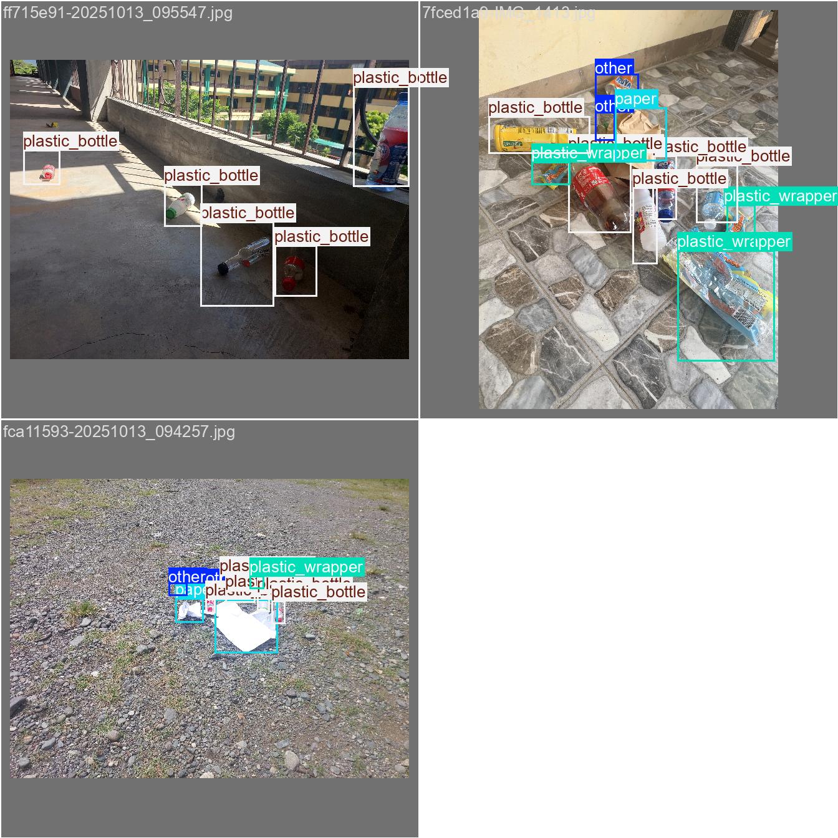
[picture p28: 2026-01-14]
ml/train/val_batch1_labels.jpg

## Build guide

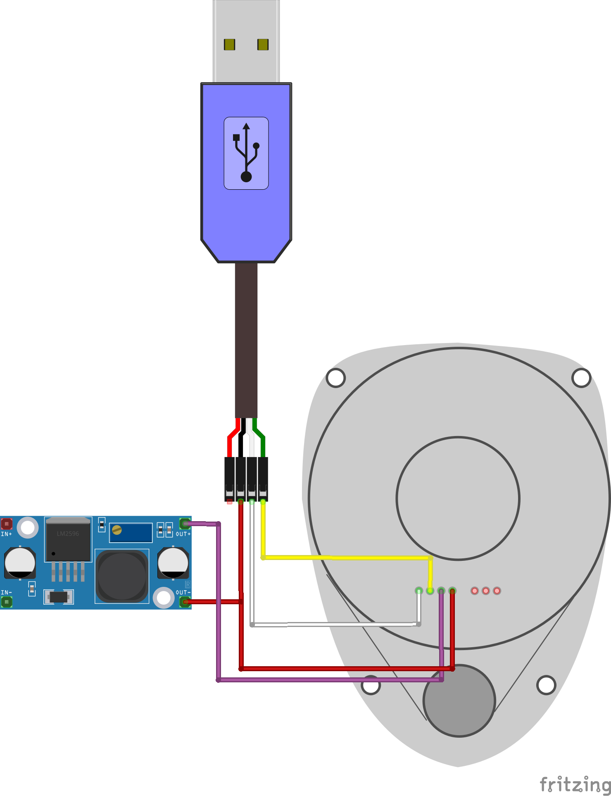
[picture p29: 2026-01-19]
diagram/Lidar_Buck_USBToTTL_Wiring.png

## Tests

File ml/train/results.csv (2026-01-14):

epoch | time | train/box_loss | train/cls_loss | train/dfl_loss | metrics/precision(B) | metrics/recall(B) | metrics/mAP50(B) | metrics/mAP50-95(B) | val/box_loss | val/cls_loss | val/dfl_loss | lr/pg0 | lr/pg1 | lr/pg2
1 | 89.9234 | 2.33252 | 3.20277 | 1.85349 | 0.41257 | 0.39318 | 0.313 | 0.11649 | 2.18098 | 3.7056 | 1.72695 | 0.0002375 | 0.0002375 | 0.0002375
2 | 113.893 | 2.11914 | 2.10921 | 1.74569 | 0.52697 | 0.40185 | 0.41907 | 0.17346 | 2.16918 | 1.89038 | 1.71374 | 0.000487017 | 0.000487017 | 0.000487017
3 | 155.428 | 2.10729 | 1.86862 | 1.70264 | 0.51665 | 0.39444 | 0.40927 | 0.15831 | 2.27163 | 1.90934 | 1.92882 | 0.00073604 | 0.00073604 | 0.00073604
4 | 196.885 | 2.08425 | 1.78645 | 1.72057 | 0.47786 | 0.35786 | 0.32077 | 0.12985 | 2.34577 | 2.40548 | 2.13398 | 0.000984567 | 0.000984567 | 0.000984567
5 | 238.493 | 2.06884 | 1.69839 | 1.71651 | 0.66502 | 0.41956 | 0.48574 | 0.21616 | 2.21696 | 1.99076 | 1.86252 | 0.0012326 | 0.0012326 | 0.0012326
6 | 278.644 | 2.04606 | 1.6143 | 1.67534 | 0.57605 | 0.50873 | 0.49958 | 0.19936 | 2.31229 | 1.7565 | 1.90956 | 0.00124381 | 0.00124381 | 0.00124381
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

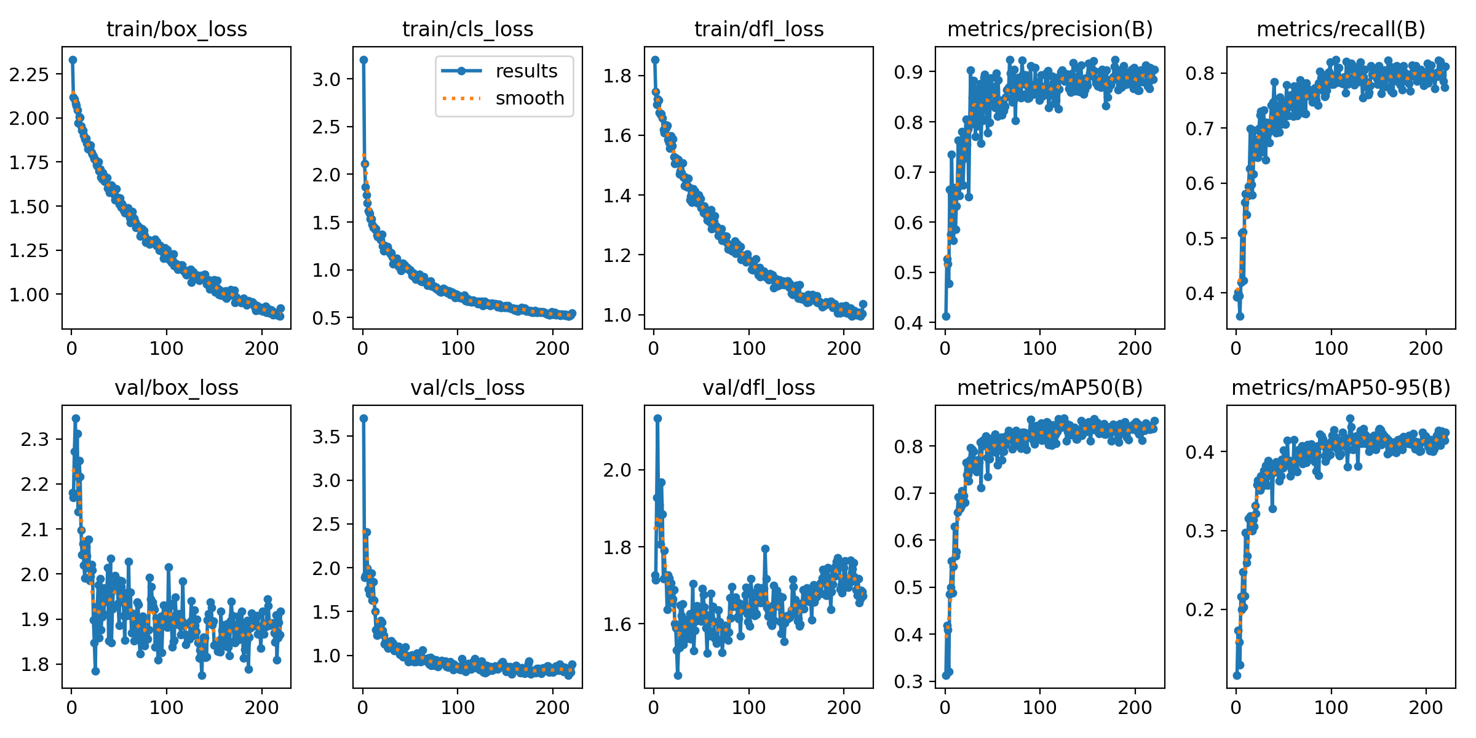
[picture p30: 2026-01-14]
ml/train/results.png

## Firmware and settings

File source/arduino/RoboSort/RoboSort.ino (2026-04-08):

#include <Wire.h>
#include "SERVO_CONFIG.h"
#include "DC_CONFIG.h"
#include "ULTRASONIC_CONFIG.h"
#include "TB6600.h"
#include "BUZZER_CONFIG.h"

ServoConfig servoConfig;
DCConfig dcConfig;
UltrasonicConfig ultrasonicConfig;
TB6600 stepper(STEPPER_DIR_PIN, STEPPER_STEP_PIN, STEPPER_ENA_PIN);
BuzzerConfig buzzerConfig;

// Limit switch variables
bool limitTestingActive = false;
bool lastArmState = HIGH;  // Track previous states (HIGH = OPEN, LOW = PRESSED)
bool lastBinState = HIGH;

// Stepper limit testing variables
bool stepperLimitTestingActive = false;
bool stepperNeedsRestart = false;
unsigned long homeStepCount = 0;
unsigned long homePositionSteps = 0; // Store the exact steps to home position

// Current bin position tracking
long currentBinPosition = 0; // Track current position in steps (0 = home)

// Autonomous navigation mode
bool autonomousMode = false;
unsigned long lastAutonomousHeartbeat = 0;
const unsigned long AUTONOMOUS_TIMEOUT = 5000; // 5 seconds timeout for autonomous mode

// Autonomous navigation state machine
// Distance limits are configured in ULTRASONIC_CONFIG.h:
//   FRONT_LEFT/RIGHT_WARN_CM      – gentle arc correction while moving forward
//   FRONT_LEFT/RIGHT_COLLISION_CM – hard stop, reverse, then spot-turn
enum AutoAvoidState {
  AVOID_FORWARD = 0,  // Moving forward; sensors monitored every cycle
  AVOID_BACKWARD,     // Reversing briefly to clear space before deciding turn
  AVOID_TURNING       // Executing corrective turn; sensors still monitored
};

AutoAvoidState avoidState    = AVOID_FORWARD;
unsigned long  avoidStateTime = 0;

const uint8_t       AUTO_FULL_SPEED  = 255; // Speed used for all autonomous moves
const unsigned long AUTO_BACKWARD_MS = 400; // How long to reverse before deciding (ms)
const unsigned long AUTO_TURN_MS     = 700; // How long to execute corrective turn (ms)

// Ultrasonic buzzer control
const int ULTRASONIC_THRESHOLD = 22; // cm
unsigned long lastUltrasonicCheck = 0;
const unsigned long ULTRASONIC_CHECK_INTERVAL = 500; // ms
bool buzzerActive = false;
bool manualBuzzerActive = false; // True while BUZZER_ON is in effect; suppresses auto-proximity beep

// --- Front obstacle avoidance (non-blocking state machine) ---
// Reads both front ultrasonic sensors every cycle — including during turns —
// so a side collision while turning is caught immediately.
//
// AVOID_FORWARD:
//   Both sensors clear           → FORWARD:255
//   One side in warning zone     → gentle arc away (LEFT:255 or RIGHT:255)
//   Either sensor in collision   → stop → BACKWARD:255 → AVOID_BACKWARD
//
// AVOID_BACKWARD:
//   After AUTO_BACKWARD_MS ms, re-read sensors and decide:
//     Both clear                 → FORWARD:255 (continue normally)
//     Left blocked only          → TURN_RIGHT:255
//     Right blocked only         → TURN_LEFT:255
//     Both blocked               → TURN toward side with more space
//
// AVOID_TURNING:
//   Execute chosen spot-turn; keep checking sensors.
//   New collision mid-turn      → immediately → AVOID_BACKWARD
//   After AUTO_TURN_MS ms        → AVOID_FORWARD
void autonomousObstacleCheck() {
  unsigned long now = millis();

  switch (avoidState) {

    // ── FORWARD ───────────────────────────────────────────────────────────
    case AVOID_FORWARD: {
      long dL = ultrasonicConfig.getAvgFrontLeftDistance();
      long dR = ultrasonicConfig.getAvgFrontRightDistance();
      bool lCollide = (dL > 0 && dL <= FRONT_LEFT_COLLISION_CM);
      bool rCollide = (dR > 0 && dR <= FRONT_RIGHT_COLLISION_CM);
      bool lWarn    = (dL > 0 && dL <= FRONT_LEFT_WARN_CM);
      bool rWarn    = (dR > 0 && dR <= FRONT_RIGHT_WARN_CM);

      if (lCollide || rCollide) {
        // Hard collision zone — stop and reverse to create maneuvering space
        dcConfig.stopAll();
        avoidState    = AVOID_BACKWARD;
        avoidStateTime = now;
        dcConfig.moveBackward(AUTO_FULL_SPEED);
        Serial.print("AVOID: collision L="); Serial.print(dL);
        Serial.print(" R="); Serial.print(dR); Serial.println(" -> BACKWARD:255");
      } else if (lWarn && !rWarn) {
        // Left approaching — gentle arc right (single-motor, robot keeps moving)
        dcConfig.turnRight(AUTO_FULL_SPEED);
      } else if (rWarn && !lWarn) {
        // Right approaching — gentle arc left
        dcConfig.turnLeft(AUTO_FULL_SPEED);
      } else if (lWarn && rWarn) {
        // Both sides in warning zone — arc toward the side with more space
        if (dL <= dR) {
          dcConfig.turnRight(AUTO_FULL_SPEED); // left closer -> arc right
        } else {
          dcConfig.turnLeft(AUTO_FULL_SPEED);  // right closer -> arc left
        }
      } else {
        dcConfig.moveForward(AUTO_FULL_SPEED);
      }
      break;
    }

    // ── BACKWARD ──────────────────────────────────────────────────────────
    case AVOID_BACKWARD: {
      if (now - avoidStateTime >= AUTO_BACKWARD_MS) {
        dcConfig.stopAll();
        // Re-read sensors after reversing to choose optimal turn direction
        long dL = ultrasonicConfig.getAvgFrontLeftDistance();
        long dR = ultrasonicConfig.getAvgFrontRightDistance();
        bool lBlocked = (dL > 0 && dL <= FRONT_LEFT_COLLISION_CM);
        bool rBlocked = (dR > 0 && dR <= FRONT_RIGHT_COLLISION_CM);

        if (!lBlocked && !rBlocked) {
          avoidState = AVOID_FORWARD;
          Serial.println("AVOID: path clear -> FORWARD:255");
        } else if (lBlocked && !rBlocked) {
          dcConfig.turnAbout(1, AUTO_FULL_SPEED); // TURN_RIGHT:255
          avoidState    = AVOID_TURNING;
          avoidStateTime = now;
          Serial.println("AVOID: left blocked -> TURN_RIGHT:255");
        } else if (!lBlocked && rBlocked) {
          dcConfig.turnAbout(0, AUTO_FULL_SPEED); // TURN_LEFT:255
          avoidState    = AVOID_TURNING;
          avoidStateTime = now;
          Serial.println("AVOID: right blocked -> TURN_LEFT:255");
        } else {
          // Both blocked — turn toward the side with more space
          // (when both dL and dR > 0 here; larger value = more space)
          if (dL >= dR) {
            dcConfig.turnAbout(0, AUTO_FULL_SPEED); // TURN_LEFT:255
            Serial.print("AVOID: both blocked (L="); Serial.print(dL);
            Serial.print(" R="); Serial.print(dR); Serial.println(") -> TURN_LEFT:255");
          } else {
            dcConfig.turnAbout(1, AUTO_FULL_SPEED); // TURN_RIGHT:255
            Serial.print("AVOID: both blocked (L="); Serial.print(dL);
            Serial.print(" R="); Serial.print(dR); Serial.println(") -> TURN_RIGHT:255");
          }
          avoidState    = AVOID_TURNING;
          avoidStateTime = now;
        }
      }
      break;
    }

    // ── TURNING ───────────────────────────────────────────────────────────
    case AVOID_TURNING: {
      // Monitor sensors during every turn — a new obstacle could appear
      long dL = ultrasonicConfig.getAvgFrontLeftDistance();
      long dR = ultrasonicConfig.getAvgFrontRightDistance();
      bool lCollide = (dL > 0 && dL <= FRONT_LEFT_COLLISION_CM);
      bool rCollide = (dR > 0 && dR <= FRONT_RIGHT_COLLISION_CM);

      if (lCollide || rCollide) {
        // New obstacle detected mid-turn — reverse again
        dcConfig.stopAll();
        avoidState    = AVOID_BACKWARD;
        avoidStateTime = now;
        dcConfig.moveBackward(AUTO_FULL_SPEED);
        Serial.println("AVOID: obstacle mid-turn -> BACKWARD:255");
        break;
      }

      if (now - avoidStateTime >= AUTO_TURN_MS) {
        dcConfig.stopAll();
        avoidState = AVOID_FORWARD;
        Serial.println("AVOID: turn done -> FORWARD:255");
      }
      break;
    }
  }
}

void setup() {
  Serial.begin(9600);
  
  // Initialize limit switches as INPUT_PULLUP
  pinMode(ARM_LIMIT_PIN, INPUT_PULLUP);
  pinMode(BIN_LIMIT_PIN, INPUT_PULLUP);
  
  servoConfig.begin();
  dcConfig.begin();
  ultrasonicConfig.begin();
  pinMode(FRONT_LEFT_TRIG, OUTPUT);
  pinMode(FRONT_LEFT_ECHO, INPUT);
  pinMode(FRONT_RIGHT_TRIG, OUTPUT);
  pinMode(FRONT_RIGHT_ECHO, INPUT);
  stepper.begin();
  buzzerConfig.begin();
  
  // Buzzer pattern: 0.5 second beep twice
  buzzerConfig.beepPattern(2, 500, 200);
  
  Serial.println("RoboSort Control System Ready!");
  buzzerConfig.startupBeep();
  Serial.println("Servo Commands: TEST, S<servo> <angle>, STEST, SSTOP, SENABLE, SDISABLE");
  Serial.println("  Lifter Commands: LIFTER UP, LIFTER DOWN, LIFTER STOP");
  Serial.println("  Arm Commands: ARM-ROTATE:<angle> (26-180 degrees, channel 0 MG996R)");
  Serial.println("  Gripper Commands: GRIP:<angle> (120-180 degrees, channel 4, default 120 degrees)");
  Serial.println("  Gripper Rotation Commands: GRIP-ROTATE:<angle> (0-180 degrees, channel 3, default 90 degrees)");
  Serial.println("  Arm Extension Commands: ARM-EXTEND:<angle> (90-180 degrees, channel 1, default 110 degrees)");
  Serial.println("  Look Commands: LOOK:<angle> (0-180 degrees, channel 2, default 90 degrees)");
  Serial.println("Motor Commands: FORWARD:<speed>, BACKWARD:<speed>, MSTOP");
  Serial.println("  Turning: LEFT:<speed>, RIGHT:<speed> (single motor turn)");
  Serial.println("  Spot Turn: TURN_LEFT:<speed>, TURN_RIGHT:<speed> (rotate in place)");
  Serial.println("  Individual: M<motor> <direction> <speed>, MSTOP");
  Serial.println("  Motors: A or B, Directions: F (forward), B (backward), S (stop), BR (brake)");
  Serial.println("  Speed: 0-255 (default: 150)");
  Serial.println("Ultrasonic Commands: UTEST, UDIST, UAVG <samples>, UDETECT <threshold>, UCTEST, UCSTOP");
  Serial.println("  Front Sensor Commands: FL_DIST (front left distance), FR_DIST (front right distance)");
  Serial.println("Stepper Commands: BIN_HOME, BIN_1, BIN_2, BIN_3, BIN_4");
  Serial.println("  BIN_HOME: Rotate CCW until BIN limit switch is triggered");
  Serial.println("  BIN_1: Move to bin 1 position (0 steps - HOME position)");
  Serial.println("  BIN_2: Move to bin 2 position (1100 steps)");
  Serial.println("  BIN_3: Move to bin 3 position (2150 steps)");
  Serial.println("  BIN_4: Move to bin 4 position (3100 steps)");
  Serial.println("Buzzer Commands: BTEST, BSUCCESS, BERROR, BWARNING, BUZZER_ON, BUZZER_OFF");
  Serial.println("Limit Switch Commands: LTEST, LREAD, LCTEST, LCSTOP");
  Serial.println("Autonomous Commands: AUTO_START, AUTO_STOP, AUTO_STATUS, AUTO_HEARTBEAT");
}

void loop() {
  stepper.update();
  servoConfig.update();
  ultrasonicConfig.update();
  buzzerConfig.update();
  dcConfig.update();  // Software PWM for motor speed control
  
  // Ultrasonic buzzer control - check every 500ms
  unsigned long currentMillis = millis();
  if (currentMillis - lastUltrasonicCheck >= ULTRASONIC_CHECK_INTERVAL) {
    lastUltrasonicCheck = currentMillis;
    
    // Get distance from sensor 1
    long distance = ultrasonicConfig.getDistance(0);  // Sensor 1 (0-indexed)
    
    if (distance > 0 && distance < ULTRASONIC_THRESHOLD && !manualBuzzerActive) {
      // Object detected within threshold - activate proximity tone (non-blocking)
      if (!buzzerActive) {
        tone(BUZZER_PIN, 1000);  // Non-blocking continuous tone instead of blocking warningBeep()
        buzzerActive = true;
      }
    } else if (!manualBuzzerActive) {
      // No object, out of range, or manual mode active - silence proximity tone
      if (buzzerActive) {
        noTone(BUZZER_PIN);
        buzzerActive = false;
      }
    }
  }
  
  // Check autonomous mode timeout
  if (autonomousMode) {
    unsigned long currentTime = millis();
    if (currentTime - lastAutonomousHeartbeat > AUTONOMOUS_TIMEOUT) {
      // Timeout - stop motors for safety
      dcConfig.stopAll();
      autonomousMode = false;
      avoidState = AVOID_FORWARD;
      Serial.println("AUTONOMOUS MODE TIMEOUT - SAFETY STOP!");
      buzzerConfig.errorBeep();
    }
  }

  // Run front obstacle avoidance when autonomous mode is active
  if (autonomousMode) {
    autonomousObstacleCheck();
  }

  // Handle continuous limit switch testing
  if (limitTestingActive) {
    bool armState = digitalRead(ARM_LIMIT_PIN);
    bool binState = digitalRead(BIN_LIMIT_PIN);
    
    // Only print when a switch is pressed (state changes from HIGH to LOW)
    if (armState == LOW && lastArmState == HIGH) {
      Serial.println("ARM LIMIT SWITCH PRESSED!");
    }
    if (binState == LOW && lastBinState == HIGH) {
      Serial.println("BIN LIMIT SWITCH PRESSED!");
    }
    
    // Update previous states
    lastArmState = armState;
    lastBinState = binState;
  }
  
  // Handle stepper limit switch testing
  if (stepperLimitTestingActive) {
    bool binState = digitalRead(BIN_LIMIT_PIN);
    if (binState == LOW) {  // Bin limit switch pressed
      stepper.emergencyStop();
      stepperLimitTestingActive = false;
      stepperNeedsRestart = false;
      Serial.println("Stepper stopped by BIN limit switch!");
      Serial.print("Exact steps to home position: ");
      Serial.println(homeStepCount);
      Serial.print("Home position calibrated: ");
      Serial.print(homeStepCount);
      Serial.println(" steps");
      
      // Store the home position for future reference
      homePositionSteps = homeStepCount;
      
      buzzerConfig.successBeep();
    } else if (!stepper.isBusy() && stepperNeedsRestart) {
      // Restart stepper in CCW direction with another batch
      stepper.setDirection(1); // CCW
      stepper.startSteps(100, 750, 1500); // Small 100-step batches
      homeStepCount += 100; // Increment step count by batch size
      // Print progress every 500 steps
      if (homeStepCount % 500 == 0) {
        Serial.print("Steps: ");
        Serial.println(homeStepCount);
      }
    }
  }
  
  if (Serial.available()) {
    String input = Serial.readStringUntil('\n');
    input.trim();
    
    // Servo commands
    if (input.equalsIgnoreCase("TEST")) {
      servoConfig.testServos();
      Serial.println("Servo test sequence complete.");
      buzzerConfig.successBeep();
    } else if (input.startsWith("S") && !input.startsWith("ST") && !input.equalsIgnoreCase("SENABLE") && !input.equalsIgnoreCase("SDISABLE")) {
      int spaceIdx = input.indexOf(' ');
      if (spaceIdx > 1) {
        int servoNum = input.substring(1, spaceIdx).toInt();
        int angle = input.substring(spaceIdx + 1).toInt();
        if (servoNum >= 0 && servoNum < NUM_SERVOS && angle >= 0 && angle <= 180) {
          servoConfig.setServoAngle(servoNum, angle);
          Serial.print("Set servo ");
          Serial.print(servoNum);
          Serial.print(" to angle ");
          Serial.println(angle);
          buzzerConfig.successBeep();
        } else {
          Serial.println("Invalid servo number or angle.");
        }
      } else {
        Serial.println("Invalid command format. Use: S<servo> <angle>");
      }
    } else if (input.equalsIgnoreCase("STEST")) {
      servoConfig.startContinuousTest();
      Serial.println("Continuous servo test started.");
    } else if (input.equalsIgnoreCase("SSTOP")) {
      servoConfig.stopContinuousTest();
      Serial.println("Continuous servo test stopped.");
    } else if (input.equalsIgnoreCase("SENABLE")) {
      servoConfig.enableServos();
      Serial.println("Servos enabled.");
    } else if (input.equalsIgnoreCase("SDISABLE")) {
      servoConfig.disableServos();
      Serial.println("Servos disabled.");
    } else if (input.equalsIgnoreCase("LIFTER UP")) {
      servoConfig.lifterUp();
    } else if (input.equalsIgnoreCase("LIFTER DOWN")) {
      servoConfig.lifterDown();
    } else if (input.equalsIgnoreCase("LIFTER STOP")) {
      servoConfig.lifterStop();
    } else if (input.startsWith("ARM-ROTATE:")) {
      int angle = input.substring(11).toInt();  // Extract angle after "ARM-ROTATE:"

      // Safety clamp: minimum 26 degrees, maximum 180 degrees
      angle = constrain(angle, 26, 180);
      servoConfig.armRotate(angle);
    } else if (input.startsWith("GRIP:")) {
      int angle = input.substring(5).toInt();  // Extract angle after "GRIP:"

      // Safe operating range: 120 (closed) .. 180 (open)
      if (angle < 120) angle = 120;
      if (angle > 180) angle = 180;
      servoConfig.gripperRotate(angle);
    } else if (input.startsWith("GRIP-ROTATE:")) {
      int angle = input.substring(12).toInt();  // Extract angle after "GRIP-ROTATE:"

      if (angle < 0) angle = 0;
      if (angle > 180) angle = 180;
      servoConfig.gripperRotationRotate(angle);
    } else if (input.startsWith("ARM-EXTEND:")) {
      int angle = input.substring(11).toInt();  // Extract angle after "ARM-EXTEND:"

      // Requested range: 90..180
      if (angle < 90) angle = 90;
      if (angle > 180) angle = 180;
      servoConfig.armExtend(angle);
    } else if (input.startsWith("LOOK:")) {
      int angle = input.substring(5).toInt();  // Extract angle after "LOOK:"
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

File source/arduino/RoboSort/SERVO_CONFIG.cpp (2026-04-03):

#include "SERVO_CONFIG.h"
#include <Wire.h>

// Typical min/max pulse lengths for servos
#define SERVO_MIN_PULSE  102
#define SERVO_MAX_PULSE  512

// Microsecond ranges matching Adafruit sample
#define SERVO_MIN_US     500
#define SERVO_MAX_US     2500
#define SERVO_NEUTRAL_US 1500

// Continuous servo timing (approximate for 360° servos)
// One full rotation takes about 1-2 seconds depending on servo
#define ROTATION_TIME_MS 1500  // Time for one full rotation

ServoConfig::ServoConfig() : pwm(Adafruit_PWMServoDriver()) {
  lifterRunning = false;
  lifterDirection = false;
  lifterStartTime = 0;
  lifterTimeout = 3000;  // Default 3 seconds
  lifterRotationCount = 0;  // Initialize rotation count
  lifterMaxRotations = 0;   // Default to time-based
  currentArmAngle = 180;  // Initialize arm to 180 degrees
  currentGripperAngle = 120;  // Initialize gripper to 120 degrees (safe minimum, default closed)
  currentGripperRotationAngle = 90;  // Initialize gripper rotation to 90 degrees (default position)
  currentArmExtensionAngle = 180;  // Initialize arm extension to 180 degrees (HOME position)
  currentLookAngle = 180;  // Initialize look servo to 180 degrees (HOME position)
  
  // Initialize mutual exclusion flags
  armExtendOperating = false;
  lookOperating = false;
  
  // Initialize homing state
  lifterHoming = false;
  homingPhase = true;  // Start with UP phase
}

void ServoConfig::begin() {
  // Configure servo OE pin
  pinMode(SERVO_OE_PIN, OUTPUT);
  
  pwm.begin();
  pwm.setOscillatorFrequency(27000000);
  pwm.setPWMFreq(50);  // Analog servos run at ~50 Hz
  delay(10);
  
  // Stop lifter servo initially
  lifterStop();
  
  // Set arm servo to default position (180 degrees)
  setServoAngle(0, 180);
  
  // Set gripper servo to default position (120 degrees, safe minimum / closed)
  // Must match currentGripperAngle initialised in the constructor (120)
  // to avoid a position-tracking desync that causes a jerk on the first command.
  setServoAngle(4, 120);
  currentGripperAngle = 120;
  
  // Set gripper rotation servo to default position (90 degrees)
  setServoAngle(3, 0);
  
  // Set arm extension servo to HOME position (90 degrees)
  setServoAngle(1, 90);
  
  // Set look servo to HOME position (180 degrees)
  setServoAngle(2, 160);
  currentLookAngle = 160;
  
  // Enable servos by default
  enableServos();
  
  Serial.println("Servo config initialized");
  
  // Perform lifter homing sequence
  // Serial.println("Starting lifter homing sequence...");
  // lifterHome();
}

void ServoConfig::update() {
  if (!lifterRunning) return;  // Nothing to do if lifter is OFF
  
  // LIFTER DOWN: Auto-stop after variable timeout or max rotations
  if (!lifterDirection) {
    unsigned long elapsed = millis() - lifterStartTime;
    int rotations = elapsed / ROTATION_TIME_MS;
    if (rotations > lifterRotationCount) {
      lifterRotationCount = rotations;
      Serial.println("LIFTER DOWN rotation count: " + String(lifterRotationCount));
    }
    bool shouldStop = false;
    if (lifterMaxRotations > 0 && lifterRotationCount >= lifterMaxRotations) {
      shouldStop = true;
      Serial.println("LIFTER DOWN complete (" + String(lifterMaxRotations) + " rotations)");
    } else if (elapsed >= lifterTimeout) {
      shouldStop = true;
      Serial.println("LIFTER DOWN complete (" + String(lifterTimeout/1000) + "s)");
    }
    if (shouldStop) {
      lifterStop();
    }
  }
  
  // LIFTER UP: Auto-stop after lifterMaxRotations rotations
  else {
    unsigned long elapsed = millis() - lifterStartTime;
    int rotations = elapsed / ROTATION_TIME_MS;
    if (rotations > lifterRotationCount) {
      lifterRotationCount = rotations;
      Serial.println("LIFTER UP rotation count: " + String(lifterRotationCount));
    }
    if (lifterRotationCount >= lifterMaxRotations) {
      lifterStop();
      Serial.println("LIFTER UP complete (" + String(lifterMaxRotations) + " rotations)");
    }
  }
}

void ServoConfig::lifterUp() {
  // Turn ON - rotate UP for exactly DEFAULT_LIFTER_MAX_ROTATIONS rotations
  lifterMaxRotations = DEFAULT_LIFTER_MAX_ROTATIONS;
  lifterTimeout = 1000000;  // Large timeout, rely on rotation count
  lifterRotationCount = 0;
  lifterStartTime = millis();
  
  pwm.setPWM(LIFTER_SERVO_CHANNEL, 0, LIFTER_UP_SPEED);
  lifterRunning = true;
  lifterDirection = true;  // UP
  Serial.println("LIFTER UP - ON (" + String(lifterMaxRotations) + " rotations)");
}

void ServoConfig::lifterDown() {
  // Always rotate DOWN exactly DEFAULT_LIFTER_MAX_ROTATIONS rotations
  lifterMaxRotations = DEFAULT_LIFTER_MAX_ROTATIONS;
  lifterTimeout = 1000000;  // Large timeout, rely on rotation count
  lifterRotationCount = 0;
  
  // Turn ON - rotate DOWN
  pwm.setPWM(LIFTER_SERVO_CHANNEL, 0, LIFTER_DOWN_SPEED);
  lifterRunning = true;
  lifterDirection = false;  // DOWN
  lifterStartTime = millis();
  Serial.println("LIFTER DOWN - ON (" + String(lifterMaxRotations) + " rotations)");
}
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

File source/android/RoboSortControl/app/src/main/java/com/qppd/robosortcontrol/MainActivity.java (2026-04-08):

package com.qppd.robosortcontrol;

import android.content.SharedPreferences;
import android.media.AudioManager;
import android.media.ToneGenerator;
import android.os.Bundle;
import android.os.Handler;
import android.os.Looper;
import android.util.Log;
import android.view.MotionEvent;
import android.view.View;
import android.widget.TextView;

import androidx.annotation.NonNull;
import androidx.appcompat.app.AppCompatActivity;
import androidx.core.content.ContextCompat;

import com.google.android.material.button.MaterialButton;
import com.google.firebase.database.DataSnapshot;
import com.google.firebase.database.DatabaseError;
import com.google.firebase.database.DatabaseReference;
import com.google.firebase.database.FirebaseDatabase;
import com.google.firebase.database.ValueEventListener;

import java.io.BufferedInputStream;
import java.io.InputStream;
import java.net.HttpURLConnection;
import java.net.URL;
import java.text.SimpleDateFormat;
import java.util.Date;
import java.util.HashMap;
import java.util.Locale;
import java.util.Map;

public class MainActivity extends AppCompatActivity {

    // Firebase
    private FirebaseDatabase database;
    private DatabaseReference commandsRef;
    private DatabaseReference feedbackRef;
    private DatabaseReference alertRef;
    private DatabaseReference autonomousModeRef;
    
    // UI Elements
    private TextView statusText;
    private TextView feedbackText;
    private TextView servo1Label, servo2Label, servo3Label, servo4Label, servo5Label;
    
    private MaterialButton btnForward, btnBackward, btnLeft, btnRight, btnStop;
    private MaterialButton btnTurnLeft, btnTurnRight;
    private MaterialButton btnLifterUp, btnLifterDown, btnLifterStop;
    private MaterialButton btnBinHome, btnBinClear, btnBin1, btnBin2, btnBin3, btnBin4;
    private MaterialButton btnPlace;
    
    // Autonomous mode
    private MaterialButton btnAutoOn, btnAutoOff;
    private TextView autoStatusLabel;
    private boolean isAutonomousMode = false;
    
    // Detection buttons
    private MaterialButton btnDetectBottle, btnDetectWrapper, btnDetectPaper, btnDetectOther;

    // Buzzer buttons
    private MaterialButton btnBuzzerOn, btnBuzzerOff;
    private TextView buzzerStatusLabel;

    // Servo buttons (replace sliders)
    private MaterialButton btnArmRotateFront, btnArmRotateBack;
    private MaterialButton btnGripOpen, btnGripClose;
    private MaterialButton btnGripRotateMinus, btnGripRotatePlus;
    private MaterialButton btnGripRotateDownDiag, btnGripRotateUpDiag, btnGripRotateVertical, btnGripRotateHorizontal;
    private MaterialButton btnArmExtendMinus, btnArmExtendPlus;
    private MaterialButton btnArmExtend180, btnArmExtend110, btnArmExtend90;
    private MaterialButton btnLookMinus10, btnLookMinus5, btnLookPlus5, btnLookPlus10;
    
    // State
    private boolean isConnected = false;
    private Handler handler;
    private ToneGenerator toneGenerator;
    
    // Servo positions
    // Match Arduino SERVO_CONFIG defaults (channels 1-5) + lifter buttons
    private int servo1Pos = 180;
    private int servo2Pos = 110;
    private int servo3Pos = 90;
    private int servo4Pos = 110;
    private int servo5Pos = 180;

    // Step sizes for +/- buttons
    private static final int STEP_GRIP_ROTATE = 10;
    private static final int STEP_ARM_EXTEND = 10;
    private static final int STEP_LOOK_LARGE = 10;
    private static final int STEP_LOOK_SMALL = 5;

    @Override
    protected void onCreate(Bundle savedInstanceState) {
        super.onCreate(savedInstanceState);
        setContentView(R.layout.activity_main);
        
        handler = new Handler(Looper.getMainLooper());
        
        // Initialize ToneGenerator for beep alerts
        try {
            toneGenerator = new ToneGenerator(AudioManager.STREAM_NOTIFICATION, 100);
        } catch (Exception e) {
            Log.e("RoboSort", "Failed to initialize ToneGenerator: " + e.getMessage());
        }
        
        // Initialize Firebase
        initializeFirebase();
        
        // Initialize UI
        initializeUI();
        
        // Setup listeners
        setupMotorControls();
        setupLifterControls();
        setupBinControls();
        setupDetectionControls();
        setupServoControls();
        setupPlaceControl();
        setupBuzzerControls();
        setupAutonomousControls();

        setupFeedbackListener();
        setupAlertListener();
    }
    
    private void initializeFirebase() {
        try {
            database = FirebaseDatabase.getInstance();
            // REMOVED: database.useEmulator("10.0.2.2", 9000); // For production use
            
            commandsRef = database.getReference("robosort/commands");
            // RPi publishes live state under robosort/status
            feedbackRef = database.getReference("robosort/status");
            alertRef = database.getReference("robosort/commands/alert");
            // Autonomous mode flag — RPi listens here and forwards to Arduino
            autonomousModeRef = database.getReference("robot/autonomous_mode");
            
            // Test connection with detailed logging
            commandsRef.child("timestamp").setValue(System.currentTimeMillis())
                .addOnSuccessListener(aVoid -> {
                    isConnected = true;
                    updateConnectionStatus(true);
                    feedbackText.setText("Firebase connected successfully!");
                })
                .addOnFailureListener(e -> {
                    isConnected = false;
                    updateConnectionStatus(false);
                    feedbackText.setText("Firebase connection failed: " + e.getMessage());
                    e.printStackTrace();
                });
        } catch (Exception e) {
            e.printStackTrace();
            updateConnectionStatus(false);
            feedbackText.setText("Firebase initialization error: " + e.getMessage());
        }
    }
    
    private void initializeUI() {
        statusText = findViewById(R.id.statusText);
        feedbackText = findViewById(R.id.feedbackText);
        
        btnForward = findViewById(R.id.btnForward);
        btnBackward = findViewById(R.id.btnBackward);
        btnLeft = findViewById(R.id.btnLeft);
        btnRight = findViewById(R.id.btnRight);
        btnStop = findViewById(R.id.btnStop);
        btnTurnLeft = findViewById(R.id.btnTurnLeft);
        btnTurnRight = findViewById(R.id.btnTurnRight);
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

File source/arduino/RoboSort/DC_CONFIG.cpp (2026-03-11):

#include "DC_CONFIG.h"

DCConfig::DCConfig() {
    // Constructor
    currentSpeedA = 0;
    currentSpeedB = 0;
    currentDirectionA = STOP;
    currentDirectionB = STOP;
    lastPWMUpdate = 0;
}

void DCConfig::begin() {
    // Initialize L298N Module 1 (Motor A) pins
    pinMode(MOTOR_A_IN1, OUTPUT);
    pinMode(MOTOR_A_IN2, OUTPUT);
    
    // Initialize L298N Module 2 (Motor B) pins
    pinMode(MOTOR_B_IN1, OUTPUT);
    pinMode(MOTOR_B_IN2, OUTPUT);
    
    // Stop all motors initially
    stopAll();
}

void DCConfig::setMotorPins(uint8_t motor, uint8_t in1State, uint8_t in2State) {
    if (motor == MOTOR_A) {
        digitalWrite(MOTOR_A_IN1, in1State);
        digitalWrite(MOTOR_A_IN2, in2State);
    } else if (motor == MOTOR_B) {
        digitalWrite(MOTOR_B_IN1, in1State);
        digitalWrite(MOTOR_B_IN2, in2State);
    }
}

void DCConfig::setSoftwarePWMSpeed(uint8_t motor, uint8_t speed) {
    speed = constrain(speed, 0, 255);
    
    if (motor == MOTOR_A) {
        currentSpeedA = speed;
    } else if (motor == MOTOR_B) {
        currentSpeedB = speed;
    }
}

void DCConfig::setMotorSpeed(uint8_t motor, int speed) {
    // Constrain speed to valid range (-255 to 255)
    speed = constrain(speed, -255, 255);
    
    if (speed > 0) {
        // Forward: IN1=HIGH, IN2=LOW
        setMotorPins(motor, HIGH, LOW);
    } else if (speed < 0) {
        // Backward: IN1=LOW, IN2=HIGH
        setMotorPins(motor, LOW, HIGH);
    } else {
        // Stop: IN1=LOW, IN2=LOW
        stopMotor(motor);
    }
}

void DCConfig::setMotorDirection(uint8_t motor, uint8_t direction) {
    if (direction == FORWARD) {
        // Forward: IN1=HIGH, IN2=LOW
        setMotorPins(motor, HIGH, LOW);
    } else if (direction == BACKWARD) {
        // Backward: IN1=LOW, IN2=HIGH
        setMotorPins(motor, LOW, HIGH);
    } else if (direction == BRAKE) {
        brakeMotor(motor);
    } else {
        // Stop: IN1=LOW, IN2=LOW
        stopMotor(motor);
    }
}

void DCConfig::moveMotor(uint8_t motor, uint8_t direction, uint8_t speed) {
    speed = constrain(speed, 0, 255);
    
    if (direction == FORWARD) {
        // Forward: IN1=HIGH, IN2=LOW
        setMotorPins(motor, HIGH, LOW);
        setSoftwarePWMSpeed(motor, speed);
        if (motor == MOTOR_A) currentDirectionA = FORWARD;
        else currentDirectionB = FORWARD;
    } else if (direction == BACKWARD) {
        // Backward: IN1=LOW, IN2=HIGH
        setMotorPins(motor, LOW, HIGH);
        setSoftwarePWMSpeed(motor, speed);
        if (motor == MOTOR_A) currentDirectionA = BACKWARD;
        else currentDirectionB = BACKWARD;
    } else if (direction == BRAKE) {
        brakeMotor(motor);
    } else {
        // Stop: IN1=LOW, IN2=LOW
        stopMotor(motor);
    }
}

void DCConfig::stopMotor(uint8_t motor) {
    // Stop: IN1=LOW, IN2=LOW
    setMotorPins(motor, LOW, LOW);
    setSoftwarePWMSpeed(motor, 0);
    if (motor == MOTOR_A) currentDirectionA = STOP;
    else currentDirectionB = STOP;
}

void DCConfig::brakeMotor(uint8_t motor) {
    // Brake: IN1=HIGH, IN2=HIGH (short brake without speed control)
    setMotorPins(motor, HIGH, HIGH);
    setSoftwarePWMSpeed(motor, 0);
    if (motor == MOTOR_A) currentDirectionA = BRAKE;
    else currentDirectionB = BRAKE;
}

void DCConfig::moveForward(uint8_t speed) {
    // Robot forward: motors rotate opposite directions since they face each other
    // INVERTED: Robot was physically flipped
    moveMotor(MOTOR_A, BACKWARD, speed);
    moveMotor(MOTOR_B, FORWARD, speed);
}
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

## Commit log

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2025-12-05 Integrate TB6600 stepper driver with NEMA 23 motor support
    - Add TB6600.h and TB6600.cpp for stepper motor control
    - Implement blocking and non-blocking stepping with continuous test modes
    - Update PINS.h with stepper pin definitions (PUL+ pin 3, DIR+ pin 4, ENA+ pin 5)
    - Add servo OE control to GPIO2 for enable/disable functionality
    - Implement continuous servo testing with back-and-forth oscillation
    - Add serial commands: SENABLE/SDISABLE, STEST/SSTOP, STEPCTEST/STEPCSTOP
    - Update RoboSort.ino with new command parsing and update loops
    - Fix compilation errors and command exclusions
    - Update README.md with current hardware specs, wiring, and usage instructions
    - Document TB6600 driver and N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
    [PINS.h, RoboSort.ino, SERVO_CONFIG.cpp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]
2025-12-06 Updated servo and stepper testing logic with 5-second intervals, added ultrasonic continuous monitoring, fixed command parsing for SENABLE/SDISABLE, and improved DC motor watchdog handling
    [DC_CONFIG.cpp, PINS.h, RoboSort.ino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]
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2025-12-07 Update RoboSort to use L298N motor drivers instead of HPMD-3.1
    - Replace E-Gizmo HPMD-3.1 with two L298N motor driver modules
    - Update pin definitions: Motor A (IN1:7, IN2:9, ENA:11), Motor B (IN1:10, IN2:11, ENB:8)
    - Remove watchdog logic from DC_CONFIG
    - Implement L298N control logic (IN1/IN2 for direction, ENA/ENB for PWM speed)
    - Update README.md with new wiring and motor control information
    - Fix MCTEST/MCSTOP command parsing issue
    [DC_CONFIG.cpp, PINS.h, RoboSort.ino]
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2025-12-22 Add buzzer configuration and integration for RoboSort Arduino
    [PINS.h, RoboSort.ino]
2025-12-22 Fix pin conflicts in PINS.h: MOTOR_B_IN2 to 12, STEPPER_DIR to 13, STEPPER_ENA to 14
    [PINS.h]
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2025-12-22 Update ultrasonic sensor pins: swap TRIG/ECHO for sensors 2-4
    [Wiring.fzz]
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2025-12-22 Fix DC_CONFIG.cpp: remove PWM functionality for motor control
    [DC_CONFIG.cpp]
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2026-01-06 Fix DC motor continuous test for opposite-facing motors
    - Modified MCTEST command to rotate motors in opposite directions for forward/backward movement
    - Updated testMotors() function to demonstrate correct robot movement patterns
    - Motors now rotate opposite to each other since they face each other
    [DC_CONFIG.cpp]
2026-01-06 Refactor DC motor control: Remove test functions and add movement commands
    - Removed MTEST, MCTEST, MCSTOP commands to reduce memory usage
    - Added 4 new movement commands: FORWARD, BACKWARD, RIGHT, LEFT
    - Motors face each other, so:
    * FORWARD/BACKWARD: motors rotate opposite directions
    * RIGHT/LEFT: motors rotate same direction for rotation
    - Removed continuous test functionality and update loop
    - Updated help text and command parsing
    - Should resolve Arduino Uno memory limit exceeded error
    [DC_CONFIG.cpp, RoboSort.ino]
2026-01-06 Fix syntax error: Add missing closing brace in LEFT command
    - Added missing '}' after LEFT command buzzerConfig.successBeep()
    - This resolves the 'expected '}' before 'else'' compilation error
    [RoboSort.ino]
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2026-01-06 Fix stepper motor direction inversion - invert DIR pin write
    [TB6600.cpp]
2026-01-06 Update ultrasonic sensor 1 pins to resolve pin conflict
    [PINS.h]
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2026-01-07 Fix STEPBIN command parsing - add to exclusion list in generic STEP handler
    [RoboSort.ino]
2026-01-07 Fix STEPBIN to rotate only CCW - use finite steps with auto-restart instead of alternating continuous test
    [RoboSort.ino]
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2026-01-07 Fix STEP command parsing - add trim() to handle leading spaces after removing 'STEP'
    [RoboSort.ino]
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2026-01-07 Correct HOME step batch size: changed from 10000 to 6000 steps per batch (approx 1 rotation)
    [RoboSort.ino]
2026-01-07 Fix HOME step counting: use 100-step batches and count from first batch, show progress every 500 steps for accurate measurement
    [RoboSort.ino]
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2026-01-07 Fix missing closing brace in BIN_MAX command block
    [RoboSort.ino]
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2026-01-07 Fix missing testServos() method definition
    [SERVO_CONFIG.cpp]
2026-01-07 Fix missing enableServos() method definition
    [SERVO_CONFIG.cpp]
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2026-01-07 Fix stray code: prevent continuous test from affecting continuous servo
    [SERVO_CONFIG.cpp]
2026-01-07 Fix SENABLE command: ensure servos are stopped when enabled
    [SERVO_CONFIG.cpp]
2026-01-07 Fix continuous servo channel 0 rotation issue
    - Corrected speedToPulse() mapping for continuous servos
    - Speed 0 now maps to pulse 307 (1.5ms neutral/stop position) instead of 375
    - Prevents lifter from continuously rotating when servos are enabled
    - Based on Adafruit PCA9685 timing: 1500μs = stop position
    [SERVO_CONFIG.cpp]
2026-01-07 PCA9685 setup per Adafruit sample; precise continuous servo neutral\n\n- Set oscillator to 27MHz and freq to 50Hz with small delay\n- Drive continuous servo via writeMicroseconds (600..1500..2400us)\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
    [SERVO_CONFIG.cpp]
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2026-01-07 Fix compilation errors: implement missing ServoConfig methods
    - Added testServos(): tests all servos (0, 90, 180) except lifter
    - Added setServoAngle(): converts angle to PWM pulse for standard servos
    - Added SERVO_OE_PIN configuration in begin() method
    - Enables servos by default on initialization
    [SERVO_CONFIG.cpp, SERVO_CONFIG.h]
2026-01-07 Fix servo continuing to move after ARM limit switch trigger
    - Added debouncing for ARM limit switch (50ms check interval)
    - Improved lifterStop() to send stop signal multiple times with delays
    - Added debug output to monitor switch state
    - Enhanced stopping mechanism to prevent servo coasting
    [SERVO_CONFIG.cpp, SERVO_CONFIG.h]
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2026-01-07 Invert lifter servo rotation direction on channel 0
    - Swap LIFTER_UP_SPEED (260 -> 360) and LIFTER_DOWN_SPEED (360 -> 260)
    - Neutral 310 is correct and working
    [SERVO_CONFIG.h]
2026-01-07 Fix servo rotation direction - swap back to original values
    - Neutral 310 correct
    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
    [SERVO_CONFIG.h]
2026-01-07 Correct lifter servo rotation direction
    - LIFTER_UP_SPEED: 360 (rotate up)
    - LIFTER_DOWN_SPEED: 260 (rotate down)
    - Neutral pulse 310 remains correct
    [SERVO_CONFIG.h]
2026-01-07 Set lifter servo to maximum speed
    - LIFTER_UP_SPEED: 0 (full speed up direction)
    - LIFTER_DOWN_SPEED: 4095 (full speed down direction)
    - Neutral 310 remains correct for stopping
    [SERVO_CONFIG.h]
2026-01-07 Revert "Set lifter servo to maximum speed"
    This reverts commit 20c5495e07275beb5f795fba6ff88f975f12be27.
    [SERVO_CONFIG.h]
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2026-01-07 Add ARM-ROTATE command for MG996R servo on channel 1
    - Added armRotate() function to control 180 MG996R servo on channel 1
    - New command: ARM-ROTATE:<angle> where angle is 0-180 degrees
    - Does not interfere with channel 0 continuous servo (lifter)
    - Added command to help text in setup
    - Validates angle range and provides feedback
    [RoboSort.ino, SERVO_CONFIG.cpp, SERVO_CONFIG.h]
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2026-01-07 Make ARM servo movement smoother and slower
    - Changed from 1-degree steps to 0.5-degree steps for smoother motion
    - Increased delay from 20ms to 30ms per step for slower movement
    - Uses floating point calculation for precise positioning
    - Prevents overshooting target angle
    [SERVO_CONFIG.cpp]
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2026-01-12 Add mutual exclusion for LOOK and ARM-EXTEND servos
    - Add armExtendOperating and lookOperating flags to prevent servo conflicts
    - Modify armExtend() to disable LOOK servo during operation
    - Modify lookRotate() to disable ARM-EXTEND servo during operation
    - Add SERVO STATUS command to check operating status and positions
    - Add getter functions for servo positions (getArmExtensionAngle, getLookAngle)
    - Improve serial output messages to indicate mutual exclusion behavior
    This ensures smooth operation by preventing simultaneous servo movements that could cause mechanical interference or power issues.
    [RoboSort.ino, SERVO_CONFIG.cpp, SERVO_CONFIG.h]
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2026-01-17 Add complete differential drive robot URDF with Gazebo simulation support
    - Create robosort.urdf.xacro with accurate dimensions (35x20x4 inches)
    - Add 12-inch drive wheels with differential drive kinematics
    - Include LD06 LiDAR sensor simulation (360 coverage, 12m range)
    - Implement Gazebo plugins for diff drive, LiDAR, and joint states
    - Add launch files for RViz visualization and Gazebo simulation
    - Create comprehensive documentation (README, QUICKSTART, params)
    - Configure proper physics (inertia, friction, collision)
    - Support both simulation (use_sim_time=true) and hardware modes
    - Integrate with existing robosort_control package
    - Add keyboard teleop support via /cmd_vel topic
    [robosort.urdf.xacro, robot_params.yaml]
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2026-01-17 Fix robot geometry: position wheels at bottom of chassis
    - Adjust base_link height to wheel_radius + body_height/2
    - Move wheel joints to -body_height/2 (bottom of chassis)
    - Update caster positions to match wheel plane
    - Fixes issue where wheels appeared in middle of 4-inch chassis
    [robosort.urdf.xacro]
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2026-01-17 Change LiDAR height to 45mm
    - Updated lidar_height from 0.06m to 0.045m (45mm)
    - LiDAR now has correct physical dimensions
    [robosort.urdf.xacro]
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2026-01-19 Fix DC motor continuous operation by removing software PWM pulsing
    [DC_CONFIG.cpp]
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2026-01-20 Remove large 3D model files (.stl, .gcode) from repository
    - Added .stl, .STL, .gcode, .GCODE patterns to .gitignore
    - Removed all .stl and .gcode files from git tracking
    - Files remain on disk for local use but are no longer version controlled
    - Reduces repository size significantly
    [RoboSort_Arm_Gripper_Hand_Extension.stl, RoboSort_Arm_Gripper_Rotator_Mount.stl, RoboSort_Arm_Gripper_Servo_Hand_Mount.stl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]
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2026-01-21 Fix: Invert LiDAR orientation to correct RViz2 movement direction
    - Rotate lidar_link 180 (π) around Z-axis in URDF
    - Fixes issue where robot moves forward in real life but backwards in RViz2
    - RF2O now calculates correct odometry direction from laser scans
    [robosort.urdf.xacro]
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2026-01-21 Revert LiDAR orientation back to original rpy='0 0 0'
    - Revert the 180 rotation that was causing movement direction issues
    - LiDAR now back to original orientation
    - Robot model orientation still needs to be fixed (wheels at front instead of back)
    [robosort.urdf.xacro]
2026-01-21 Move LiDAR to rear position to reverse map orientation
    [robosort.urdf.xacro]
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2026-01-21 Fix wheel joint axes for correct forward/backward motion
    [robosort.urdf.xacro]
2026-01-21 Fix wheel macro to use explicit axis parameters
    [robosort.urdf.xacro]
2026-01-21 Revert wheel axes to original for correct motion
    [robosort.urdf.xacro]
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2026-01-21 Loosen inactive servo during ARM-EXTEND and LOOK operations instead of holding position
    [SERVO_CONFIG.cpp]
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2026-01-22 Implement autonomous obstacle avoidance system
    - Add LIDAR-based obstacle detection using LD06 sensor
    - Implement left vs right avoidance logic with angle-distance analysis
    - Create Arduino autonomous mode with safety watchdog timer
    - Add motor control commands: FORWARD, BACKWARD, TURN_LEFT, TURN_RIGHT, etc.
    - Create comprehensive navigation system with configurable behavior modes
    - Add test suite for individual components and full system integration
    - Include documentation and quick-start scripts
    Files added:
    - obstacle_avoidance.py: Core avoidance algorithm
    - navigate.py: Main autonomous navigation controller
    - nav_config.py: Centralized configuration system
    - test_navigation.py: Complete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
    [RoboSort.ino]
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2026-01-22 Fix DC motor direction for LEFT/RIGHT commands
    - Corrected LEFT command: now only left motor forward (right motor stopped)
    - Corrected RIGHT command: now only right motor forward (left motor stopped)
    - Updated comments and documentation to reflect proper motor assignments
    - DC_CONFIG.h/cpp: Swapped motor assignments for turnLeft/turnRight methods
    - navigate.py: Updated method comments
    - NAVIGATION_README.md: Updated command descriptions and examples
    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
    [DC_CONFIG.cpp]
2026-01-22 Clarify motor-to-wheel mapping for LEFT/RIGHT commands
    - Updated comments to clarify: MOTOR_A (left DC motor) = RIGHT wheel
    - MOTOR_B (right DC motor) = LEFT wheel
    - Fixed turnLeft/turnRight logic comments to reflect correct wheel control
    - Updated turnAbout function comments for spot turns
    - Added motor-to-wheel mapping documentation
    - Updated PINS.h and DC_CONFIG.h with wheel assignments
    - Corrected NAVIGATION_README.md examples and descriptions
    The actual motor control logic was already correct, but comments and
    documentation now clearly show the wheel assignments.
    [DC_CONFIG.cpp, PINS.h]
2026-01-22 Fix TURN_LEFT/TURN_RIGHT commands for proper rotation
    - Modified turnAbout() function to use same-direction motor movement
    - TURN_LEFT: both motors backward (left rotation)
    - TURN_RIGHT: both motors forward (right rotation)
    - Updated documentation to clarify LEFT/RIGHT vs TURN_LEFT/TURN_RIGHT behavior
    - LEFT/RIGHT: single motor turns, TURN_LEFT/TURN_RIGHT: spot rotations
    [DC_CONFIG.cpp]
2026-01-22 Fix LEFT command direction - use BACKWARD for MOTOR_B to achieve forward movement
    - Modified turnLeft() to use BACKWARD direction for MOTOR_B (left wheel)
    - This accounts for motors facing each other - BACKWARD for left motor = forward robot movement
    - Updated comments in header file and documentation
    - LEFT command now moves robot forward as expected
    [DC_CONFIG.cpp]
2026-01-22 Fix TURN_LEFT/TURN_RIGHT to use same motors as LEFT/RIGHT commands
    - Modified turnAbout() to use single motor rotation instead of both motors
    - TURN_LEFT now uses MOTOR_B (left wheel) same as LEFT command
    - TURN_RIGHT now uses MOTOR_A (right wheel) same as RIGHT command
    - Updated documentation to reflect single motor rotation behavior
    - TURN commands now follow same motor pattern as LEFT/RIGHT for consistency
    [DC_CONFIG.cpp]
2026-01-22 Revert TURN_LEFT/TURN_RIGHT to use both motors with correct directions
    - Modified turnAbout() back to using both motors for spot rotation
    - TURN_LEFT: both motors BACKWARD (left rotation) - direction was correct
    - TURN_RIGHT: both motors FORWARD (right rotation) - direction was correct
    - Updated documentation to reflect both motor rotation behavior
    - Kept the correct motor directions established in previous fixes
    [DC_CONFIG.cpp]
2026-01-22 Reverse TURN_LEFT/TURN_RIGHT motor directions
    - TURN_LEFT now uses both motors BACKWARD for left rotation
    - TURN_RIGHT now uses both motors FORWARD for right rotation
    - Reversed the motor directions as requested by user
    [DC_CONFIG.cpp]
2026-01-22 Apply correct DC_CONFIG.cpp with proper motor control functions
    - Fixed incomplete turnLeft() and turnRight() functions with differential turning
    - Corrected turnAbout() to use opposite motor directions for spot turning
    - TURN_LEFT: left wheel backward, right wheel forward (opposite directions)
    - TURN_RIGHT: left wheel forward, right wheel backward (opposite directions)
    - Updated comments to reflect proper motor behavior
    [DC_CONFIG.cpp]
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2026-01-22 Fix motor control for LEFT/RIGHT commands
    - Add stopAll() before turnLeft/turnRight/turnAbout to prevent motors staying active
    - Ensure LEFT command: only left wheel forward, right wheel stopped
    - Ensure RIGHT command: only right wheel forward, left wheel stopped
    - Prevent one motor from remaining active when switching to single-wheel turns
    [DC_CONFIG.cpp]
2026-01-22 Fix Arduino DC_CONFIG.cpp compilation errors
    - Add missing closing brace for turnLeft function
    - Properly structure turnRight function declaration
    - Fix syntax errors that were causing compilation failures
    [DC_CONFIG.cpp]
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2026-01-27 Fix syntax error in rc_controler.py - replace escaped quotes with proper triple quotes
    [rc_controler.py]
2026-01-27 Update Firebase database URL to correct RTDB URL
    - Change databaseURL from https://robosortcontrol.firebaseio.com
    - To https://robosortcontrol-default-rtdb.firebaseio.com
    [rc_controler.py]
2026-01-27 Fix TypeError in Firebase stream handler by adding null check for data parameter
    [rc_controler.py]
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2026-01-27 Align Android app with Arduino command protocol
    - Change motor commands from LEFT/RIGHT to TURN_LEFT/TURN_RIGHT for spot turning
    - Update all motor speeds from 200/150 to 255 for full power
    - Fix RPi command formatter to send correct Arduino format (FORWARD:255, TURN_LEFT:255, etc.)
    - Fix servo command format to match Arduino expectation (S1 90 instead of S:1:90)
    - Add debug logging to RPi for sent commands
    - Commands now correctly flow: Android -> Firebase -> RPi -> Arduino
    [MainActivity.java, rc_controler.py]
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2026-01-27 Fix Android Firebase connection issue
    - Remove Firebase emulator line to use production database
    - Add detailed error logging for connection failures
    - Add command sending feedback to debug button presses
    - Fix success/failure listener logic in sendMotorCommand
    [MainActivity.java]
2026-01-27 Fix motor command processing in Firebase stream listener
    - Change command comparison to compare direction strings instead of command objects
    - Add debug logging to show received commands
    - Fix issue where STOP commands were overriding FORWARD commands due to object comparison
    [rc_controler.py]
2026-01-27 Add comprehensive Firebase stream debugging and fix stream reference
    - Store stream object reference to keep it alive
    - Add detailed logging for all stream events and data
    - Log stream listener initialization
    - Add debug output for command processing and skipping
    - Fix stream cleanup in shutdown method
    - This will help diagnose why stream events aren't being received
    [rc_controler.py]
2026-01-27 Fix Firebase stream data processing to handle direct motor command structure
    [rc_controler.py]
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2026-01-27 Fix RPiArduino serial comms: match 9600 baud, add reset delay, make baud configurable
    [rc_controler.py]
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2026-01-27 Integrate MJPEG camera streaming into rc_controler.py
    - Embed Flask MJPEG server in RC controller for single-command operation
    - Share camera frames between local display and streaming
    - Add --stream/--no-stream flags and stream host/port options
    - Stream serves /video endpoint and test page at /
    - Background thread prevents blocking RC operations
    [rc_controler.py]
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2026-01-27 Add safety check to prevent LIFTER DOWN when ARM-EXTEND < 110
    - RPi rc_controler.py: Block LIFTER DOWN if ARM-EXTEND servo4 < 110
    - Android MainActivity.java: Client-side safety check with user feedback
    - Double protection: Both client and server validate before sending command
    - Safety message: 'Extend arm first before lowering lifter!'
    [rc_controler.py]
2026-01-28 Update SERVO_CONFIG.cpp default positions
    - Fix servo 4 comment: ARM-EXTEND default is 110 (was incorrectly commented as 90)
    - Change servo 5 default: LOOK servo now initializes to 180 instead of 90
    [SERVO_CONFIG.cpp]
2026-01-28 Replace Android servo sliders with button controls
    - Android: Replace servo sliders with buttons (FRONT/BACK, OPEN/CLOSE, +/-)
    - Enforce ranges: ARM-EXTEND 110..180, others 0..180
    - Set LOOK default to 180 in Android
    - Arduino: Keep currentLookAngle aligned with LOOK default 180
    - Git: Stop ignoring entire Android app; ignore only local/secrets
    [MainActivity.java, SERVO_CONFIG.cpp]
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2026-01-30 Add buzzer pattern: 0.5 second beep twice in setup() after buzzer begin
    [RoboSort.ino]
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2026-02-01 Add CLEAR button for object detection
    - Added btnDetectClear button to Android app
    - CLEAR button sends 'none' object type to RPi
    - RPi resets detected_object to 'None' when clear command received
    - Camera display will show 'Detected: None' after clearing
    - Red button color for clear action visibility
    [MainActivity.java, rc_controler.py]
2026-02-01 Fix syntax error in display_camera method and add headless display support
    [rc_controler.py]
2026-02-01 Fix syntax error in display_camera method causing imshow crash
    [rc_controler.py]
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2026-02-01 Fix PLACE sequence routing to check path for /place - Add path-based handler for place_sequence commands - Now correctly detects and executes PLACE sequence from /place path
    [rc_controler.py]
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2026-02-04 Add GPIO button alert system - RPi GPIO17 button sends beep to Android and auto-resets
    [MainActivity.java, rc_controler.py]
2026-02-05 feat: Add GPIO button alert and ultrasonic buzzer control
    - Add GPIO button monitoring on RPi GPIO17 to trigger 3x beep alerts on Android
    - Implement ultrasonic sensor monitoring with buzzer control (<22cm = beep, >=22cm = silent)
    - Modify Android MainActivity to play 3 consecutive beep tones instead of single beep
    - Add continuous ultrasonic monitoring thread in rc_controler.py
    - Update Arduino RoboSort.ino with automatic buzzer control based on distance threshold
    [MainActivity.java, RoboSort.ino, rc_controler.py]
2026-02-12 Clear pending Firebase commands on startup to prevent old BIN commands from auto-detecting objects
    [rc_controler.py]
2026-02-12 Skip auto-detect detected_object on first stream event for BIN commands
    [rc_controler.py]
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2026-03-10 Add autonomous obstacle avoidance with front ultrasonic sensors and mode control
    [MainActivity.java, PINS.h, RoboSort.ino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]
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2026-03-11 Implement continuous autonomous navigation with mean-averaged ultrasonic obstacle avoidance
    [DC_CONFIG.cpp, RoboSort.ino, ULTRASONIC_CONFIG.cpp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]
2026-03-11 Invert motor directions in DCConfig due to robot flip
    [DC_CONFIG.cpp]
2026-03-11 Fix inverted left/right controls in DCConfig
    [DC_CONFIG.cpp]
2026-03-11 Fix linker error: include ULTRASONIC_CONFIG.cpp to ensure implementation is compiled
    [RoboSort.ino]
2026-03-11 Fix left turn: right wheel now goes forward for LEFT:255 command
    [DC_CONFIG.cpp]
2026-03-11 fix: add AUTO_HEARTBEAT thread for autonomous mode, improve collision logic, android auto controls
    [MainActivity.java, RoboSort.ino, ULTRASONIC_CONFIG.h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]
2026-03-11 feat: rich imshow overlay - movement label, ultrasonic bars, avoid action, auto badge
    [rc_controler.py]
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2026-03-13 fix: ensure heartbeat thread is always running during AUTO mode on every command
    [rc_controler.py, robosort_ctrl_mnl.py]
2026-03-13 fix: correct Firebase path from robosortv2 to robosort in rc_controler.py
    [rc_controler.py]
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2026-03-30 feat: manual buzzer ON/OFF control end-to-end (Android, Pi, Arduino)
    [MainActivity.java, RoboSort.ino, robosort_ctrl_mnl.py]
2026-03-30 fix: remove successBeep from motor movement commands to stop buzzer noise during driving
    [RoboSort.ino]
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2026-04-03 Fix gripper servo jitter: remove Serial.print from step loop, sync initial position to 110° for smooth and stable movement
    [SERVO_CONFIG.cpp]
2026-04-03 Fix GRIP servo logic: enforce 120-180° range, prevent fallback to 0°, update all controllers and docs. Gripper now only moves and holds within safe range, never resets to 0° unless explicitly command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
    [RoboSort.ino, SERVO_CONFIG.cpp, rc_controler.py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]
2026-04-09 Fix LIFTER UP: clamp LIFTER_UP_SPEED to valid servo pulse range (was 530, now 490)
    [SERVO_CONFIG.h]
2026-04-13 fix: LIFTER UP/DOWN now use 6 rotations, no limit switch; update Python PLACE sequence timing
    [SERVO_CONFIG.h, robosort_ctrl_mnl.py]

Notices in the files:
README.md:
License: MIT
